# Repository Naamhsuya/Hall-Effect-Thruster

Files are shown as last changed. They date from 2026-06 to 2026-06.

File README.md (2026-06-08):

Hall Effect Thruster — Magnetic Field Model

[README.md](https://github.com/user-attachments/files/28627607/README.md)
# Hall Effect Thruster (HET) — Research & Design Project

Scaling analysis, magnetostatic modeling, and CAD design of a Hall Effect Thruster, with an accompanying research manuscript currently under peer review at the **Journal of Engineering and Applied Sciences, Springer Nature**.








---

## Repository Structure

```
├── CAD/                  # SolidWorks part and assembly files
├── FEMM/                 # Magnetic field simulation files (FEMM format)
├── Scaling/              # Thruster scaling analysis spreadsheet (.xlsx)
├── Gallery/              # Miscellaneous project images and visuals
└── REFERENCES.md         # Full list of papers and resources used
```

---

## Project Overview

### 1. Scaling Analysis
Thruster dimensions and operating parameters were derived from Hall thruster scaling laws. The scaling methodology closely follows the work of **Mahajan et al. (2025)** on 500W-class Hall thruster development. The spreadsheet in `Scaling/` documents the computed parameters used to size the thruster geometry, including discharge channel dimensions, propellant flow rates, and power estimates.

### 2. Magnetic Modeling
Magnetostatic simulations were performed using [FEMM (Finite Element Method Magnetics)](https://www.femm.info/wiki/HomePage). The `.FEM` files in `FEMM/` contain the magnetic circuit geometry, material definitions, and boundary conditions used to shape and optimize the radial magnetic field profile across the discharge channel.

### 3. CAD Design
A 3D model of the thruster was developed in **SolidWorks** based on the scaled parameters and magnetic modeling results. The `CAD/` folder contains individual part files and the full assembly.

### 4. Gallery
The `Gallery/` folder contains miscellaneous project visuals including simulation plots, design iterations, and reference images.
<p align="center">
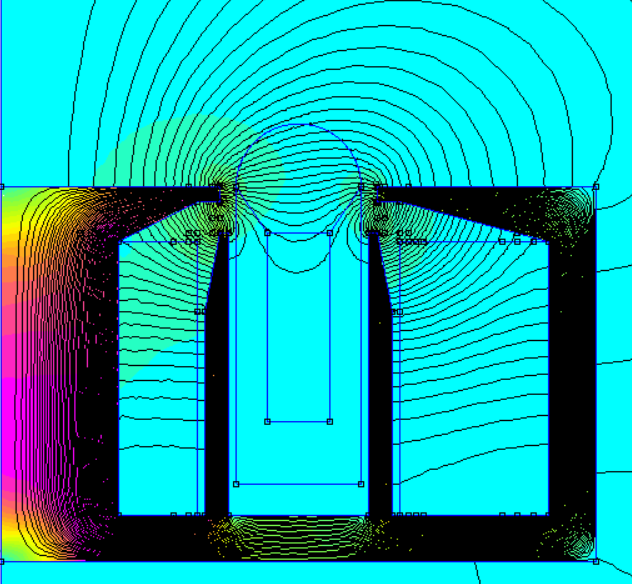
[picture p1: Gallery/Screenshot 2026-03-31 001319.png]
FEMM Magnetic Field Topology
  
  &nbsp;&nbsp;
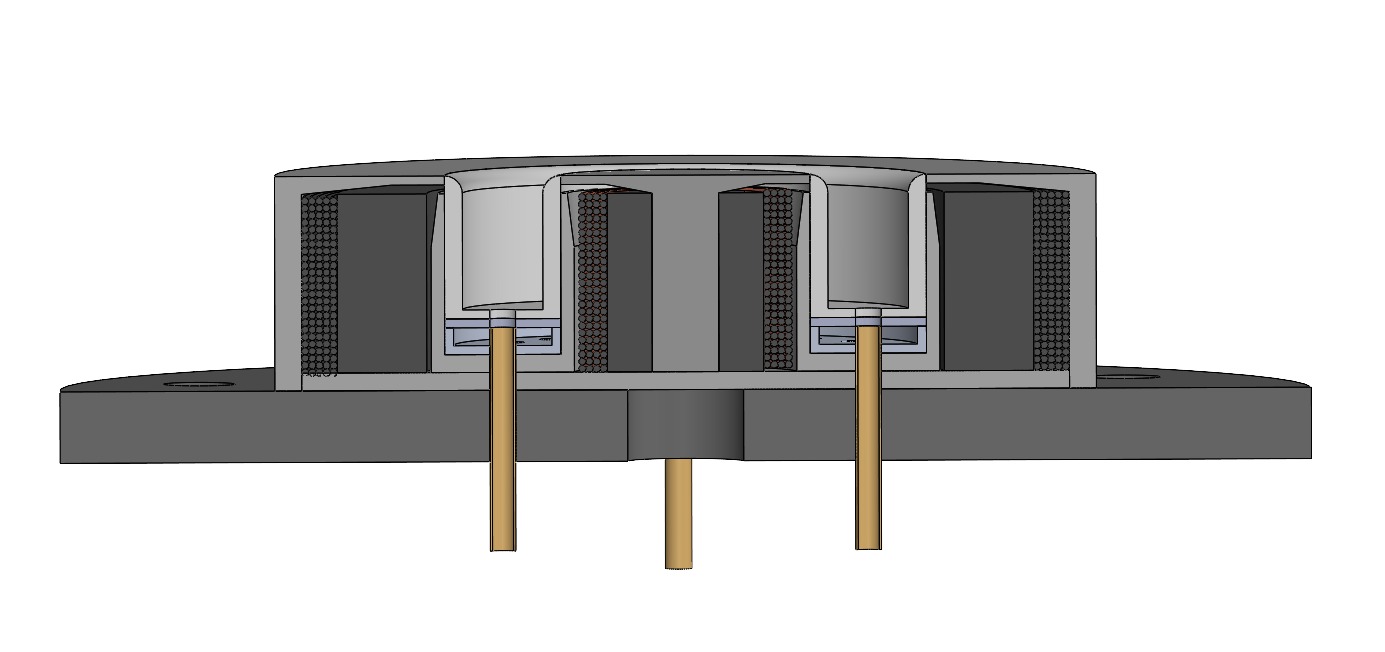
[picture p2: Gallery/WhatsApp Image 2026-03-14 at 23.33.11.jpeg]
SolidWorks Section View
  
</p>
<p align="center">
  <em>Left: FEMM 2D axisymmetric magnetic field topology near channel exit &nbsp;|&nbsp; Right: SolidWorks section view of thruster assembly</em>
</p>

<p align="center">
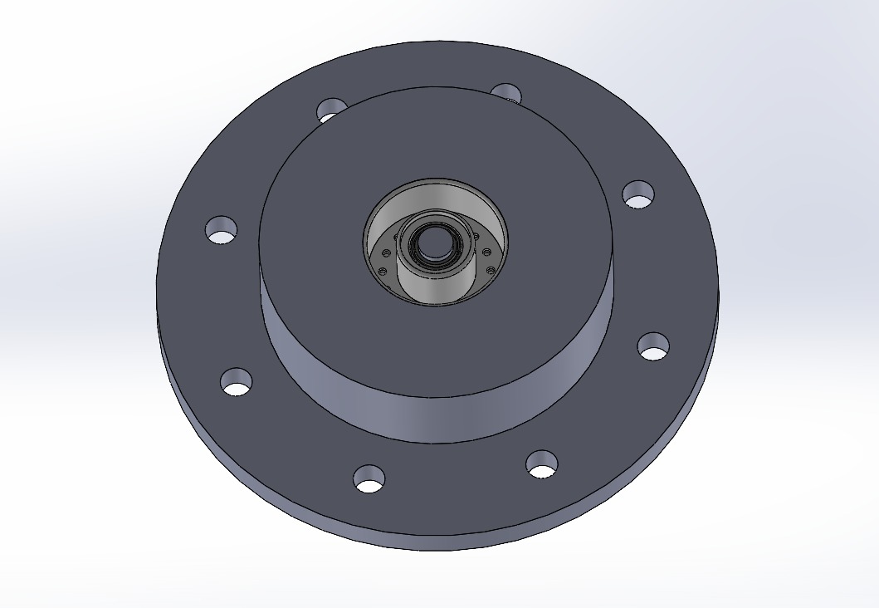
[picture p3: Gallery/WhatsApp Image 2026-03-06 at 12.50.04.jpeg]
Isometric CAD View
  
  &nbsp;&nbsp;
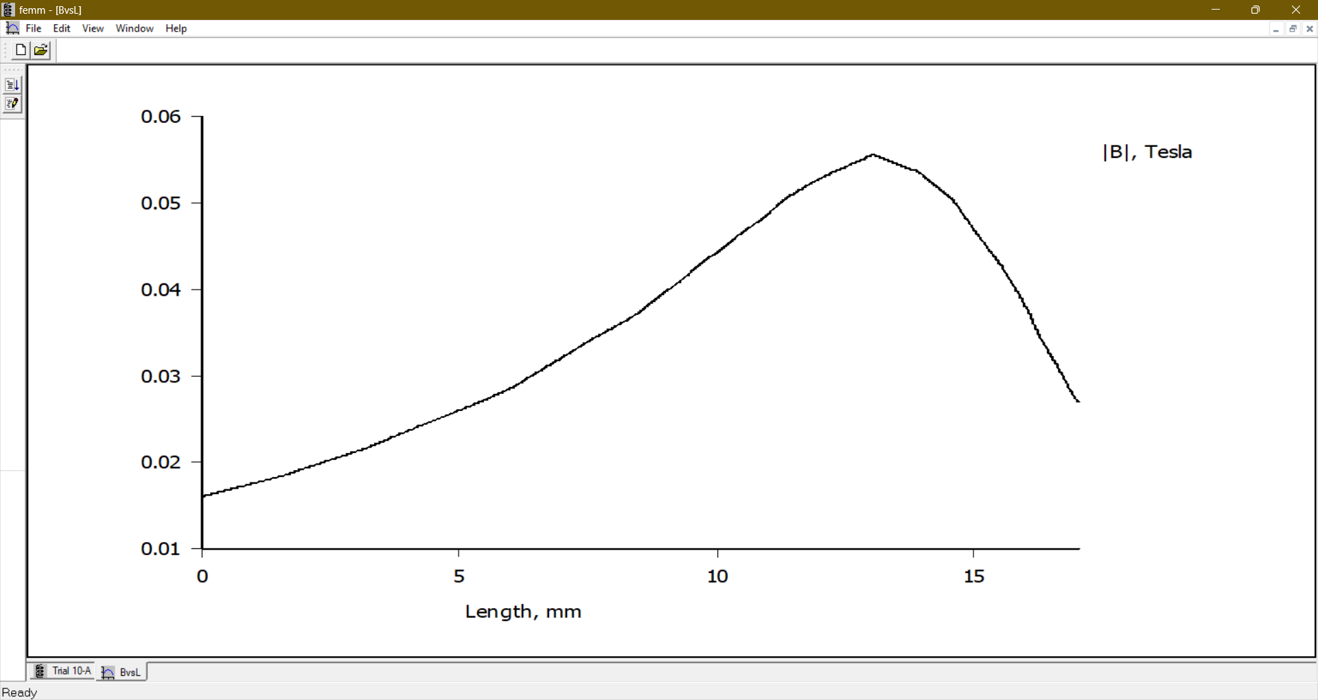
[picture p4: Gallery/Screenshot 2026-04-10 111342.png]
Channel Length vs Magnetic Field Strength
  
</p>
<p align="center">
  <em>Left: Isometric external view of thruster assembly &nbsp;|&nbsp; Right: Channel length vs magnetic field strength regression</em>
</p>
---

## Tools Used

| Tool | Purpose |
|---|---|
| FEMM | Magnetostatic finite element analysis |
| SolidWorks | 3D part and assembly modeling |
| Microsoft Excel | Scaling law calculations |

---

## Results & Key Findings

### Scaling Output — Channel Geometry

A regression-based scaling approach derived from a compiled dataset of 18 low-power Xenon Hall Effect Thrusters was applied to the target operating point of **200 W** and **250 V**. The procedure yielded the following discharge channel dimensions:

| Parameter | Value |
|---|---|
| Mean channel diameter | 38 – 40 mm |
| Channel length | 19 – 21 mm |
| Channel width (height) | ~9 mm |
| Discharge voltage | 250 V |
| Discharge power | 200 W |
| Propellant | Xenon (SPT-type) |

These dimensions place the thruster within the geometric range of compact low-power Xenon HETs, consistent with the SPT-50M and KHT-50 class devices used as reference configurations in the scaling dataset.

### Magnetic Circuit — FEMM Results

A 2D axisymmetric FEMM simulation was used to develop and refine the magnetic circuit. The circuit used an AISI 1020 soft magnetic steel core with inner and outer poles arranged to concentrate the radial magnetic field near the channel exit — the region where electron confinement and Hall current formation are most critical for stable discharge. The design ensured:

- Radial magnetic field concentrated near the channel exit plane
- Inner pole operating below saturation threshold (verified against the AISI 1020 B-H curve)
- Electron Larmor radius much smaller than the channel length (re ≪ L)
- Ion Larmor radius large enough to allow axial acceleration without premature wall contact (ri ≫ L)

### CAD Design — Representative Model

A SolidWorks assembly was developed to verify that all thruster components could be integrated within the 200 W class envelope. Key material selections:

| Component | Material |
|---|---|
| Discharge channel | Boron Nitride (BN) |
| Magnetic core & poles | AISI 1020 soft magnetic steel |
| Structural base plate | Aluminium |
| Electromagnet windings | Copper (0.8 mm diameter) |

### Predicted Performance

Theoretical performance was estimated from the finalised geometry using scaling relations from Lee et al. (2019):

| Parameter | Value |
|---|---|
| Anode mass flow rate | 1.08 mg/s |
| Thrust force | 15.24 mN |
| Specific impulse (Isp) | 1440.28 s |

> **Note:** These are theoretical estimates derived from empirical scaling relations and have not yet been experimentally validated. The design is intended as a preliminary baseline for future fabrication and vacuum testing.

---

## Key References

This project draws heavily from the following works. A complete reference list of all 116 sources is in [`REFERENCES.md`](./REFERENCES.md).

**Primary methodology reference:**
> Mahajan, B., Troise, L., Giannetti, V., Ferrato, E., & Andreussi, T. (2025). *Development of a 500W-class high-voltage argon-fed Hall thruster.* Journal of Electric Propulsion.

**Scaling laws & design:**
> Dannenmayer, K., & Mazouffre, S. (2008). *Sizing of Hall Effect Thrusters with Input Power and Thrust Level: An Empirical Approach.*

> Shagayda, A. A., & Gorshkov, O. A. (2013). *Hall-thruster scaling laws.* Journal of Propulsion and Power, 29(2), 466–474. https://doi.org/10.2514/1.B34650

> Andrenucci, M., Battista, F., & Piliero, P. *Hall Thruster Scaling Methodology.*

**Foundational textbook:**
> Goebel, D. M., & Katz, I. *Fundamentals of Electric Propulsion: Ion and Hall Thrusters.* JPL Space Science and Technology Series.

---

## Related Publications

### Review Paper — *Published Preprint*
**Review of Electric Propulsion Technologies with Emphasis on Hall Effect Thruster for Satellite Operations**
Ayushmaan Badola, Drishya Sarilla
*Engineering Archive (engrXiv), April 2026*
🔗 [https://doi.org/10.31224/6806](https://doi.org/10.31224/6806)

A comparative review of five electric propulsion technologies — PPTs, Electrospray Thrusters, Gridded Ion Engines, Vacuum-Arc Thrusters, and Hall Effect Thrusters — evaluated across thrust-to-power ratio, specific impulse, system complexity, and flight heritage. Establishes HETs as the most viable baseline technology for small satellite propulsion.

---

### Research Manuscript — *Under Peer Review*
An original research manuscript based on this design project has been submitted to the **Journal of Engineering and Applied Sciences, Springer Nature**, and is currently under peer review.

---

## References & Resources

A complete list of all 116 papers, textbooks, and resources used throughout this project is available in [`REFERENCES.md`](./REFERENCES.md).

> The full reference library (~800MB of PDFs) could not be hosted here due to file size. The reference list links to original sources and DOIs wherever available.

---

## Author

**Ayushmaan Badola**

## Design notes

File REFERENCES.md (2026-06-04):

# References & Resources

Complete list of papers, textbooks, and resources used throughout this project. Links to DOIs and source URLs are provided where available.

---

1. Alifano, F., Panelli, M., & Battista, F. (2023). Preliminary Design Tool for Medium-Low-Power Gridded Ion Thrusters. *Applied Sciences (Switzerland), 13*(9). https://doi.org/10.3390/app13095600

2. Andrenucci, M., Battista, F., & Piliero, P. (n.d.). *Hall Thruster Scaling Methodology.*

3. Antropov, N. N., et al. (2017). Development of Russian Next-generation Ablative Pulsed Plasma Thrusters. *Procedia Engineering, 185*, 53–60. https://doi.org/10.1016/j.proeng.2017.03.291

4. Aoyagi, J., et al. (2025). Series development of coaxial pulsed plasma thruster from 1 J to 8 J. *Journal of Electric Propulsion, 4*(1). https://doi.org/10.1007/s44205-025-00135-z

5. Baird, M. (2016). *Designing an Accessible Hall Effect Thruster.* https://scholarworks.wmich.edu/honors_theses/2697

6. Battista, F., Andrenucci, M., et al. (2007). *High Power Hall Thrusters Design Options.* 30th International Electric Propulsion Conference. https://www.researchgate.net/publication/237630343

7. Battista, F., Andrenucci, M., et al. (2007). *A Review of the Hall Thruster Scaling Methodology.* https://www.researchgate.net/publication/242248186

8. Bock, D., et al. (2016). Development and testing of electric propulsion systems at TU Dresden. *52nd AIAA/SAE/ASEE Joint Propulsion Conference.* https://doi.org/10.2514/6.2016-4848

9. Boeuf, J. P. (2017). Tutorial: Physics and modeling of Hall thrusters. *Journal of Applied Physics, 121*(1). https://doi.org/10.1063/1.4972269

10. Chhavi, C., & Walker, M. L. R. (2024). Review of non-conventional Hall effect thrusters. *Journal of Electric Propulsion, 3*(1). https://doi.org/10.1007/s44205-024-00073-2

11. Choueiri, E. Y. (2009). New dawn for electric rockets. *Scientific American, 300*(2), 58–65. https://doi.org/10.1038/scientificamerican0209-58

12. Conversano, R. W., et al. (n.d.). *Overview of the Ascendant Sub-kW Transcelestial Electric Propulsion System (ASTRAEUS).*

13. Conversano, R. W., et al. (2015). Development and initial testing of a magnetically shielded miniature hall thruster. *IEEE Transactions on Plasma Science, 43*(1), 103–117. https://doi.org/10.1109/TPS.2014.2321107

14. Dannenmayer, K. (2013). *Scaling laws and electron properties in Hall effect thrusters.* https://theses.hal.science/tel-00797732

15. Dannenmayer, K., & Mazouffre, S. (2008). Sizing of Hall effect thrusters with input power and thrust level: An Empirical Approach. https://www.researchgate.net/publication/2212736

16. Dannenmayer, K., Mazouffre, S. (n.d.). Elementary scaling laws for the design of low and high power Hall effect thrusters. https://doi.org/10.1051/eu

17. Daren, Y., Yongjie, D., & Zhi, Z. (2005). Improvement on the scaling theory of the stationary plasma thruster. *Journal of Propulsion and Power, 21*(1), 139–143. https://doi.org/10.2514/1.5901

18. de Grys, K., et al. (n.d.). *Development and Testing of a 4500 Watt Flight Type Hall Thruster and Cathode.*

19. Eslava, S. A., et al. (2014). *Design of a Micro-Pulsed Plasma Thruster for 3U Cubesat.* https://www.researchgate.net/publication/261448478

20. Esteves, B., et al. (n.d.). *Experimental and numerical investigation of a gridded ion thruster running with different propellants (I2, Xe, Kr, Ar).*

21. Ferreira, J. L., et al. (2019). Hall plasma thruster development for micro and nano satellites. *Journal of Physics: Conference Series, 1365*(1). https://doi.org/10.1088/1742-6596/1365/1/012026

22. Forster, R., Szulc, M., & Schein, J. (2024). Design of a power processing unit with integrated telemetry for a vacuum arc thruster. *Journal of Electric Propulsion, 3*(1). https://doi.org/10.1007/s44205-024-00074-1

23. Garcia, A. O., Tang, H., & Ren, J. (2020). Scaling Model for SPT and TAL Thrusters. *IEEE Transactions on Plasma Science, 48*(1), 86–98. https://doi.org/10.1109/TPS.2019.2958187

24. Gascon, N., et al. (n.d.). *Preliminary Testing of a Coaxial Hall Thruster with a Diamond Nose Cone.*

25. Giammarinaro, G., & Marconcini, F. (n.d.). *Hall Thruster Scaling — Electric Propulsion II.*

26. Giannetti, V., et al. (2022). Experimental scaling laws for the discharge oscillations and performance of Hall thrusters. *Journal of Applied Physics, 131*(1). https://doi.org/10.1063/5.0070945

27. Goebel, D. M., & Katz, I. (n.d.). *Fundamentals of Electric Propulsion: Ion and Hall Thrusters.* JPL Space Science and Technology Series.

28. Goebel, D. M., Katz, I., & Mikellides, I. G. (n.d.). *Fundamentals of Electric Propulsion, 2nd Edition.*

29. Gondol, N., Drobny, C., Neunzig, O., & Tajmar, M. (n.d.). *Development and Characterization of a Miniature Hall-Effect Thruster using Permanent Magnets.*

30. Gonzalez Del Amo, J. (2019). *Electric Propulsion at the European Space Agency (ESA).* https://www.researchgate.net/publication/335985184

31. Guidi, C., et al. (n.d.). *Iodine Hollow Cathode Development for Electric Propulsion.*

32. Gur Kokal, U. (n.d.). *Development of a Mili-Newton Level Thrust Stand for Thrust Measurements of Electric Propulsion Systems and UK90 Hall Effect Thruster.*

33. Hall, S. J., et al. (n.d.). *High-Power Performance of a 100-kW Class Nested Hall Thruster.*

34. Hofer, R. R. (2004). *Development and Characterization of High-Efficiency, High-Specific Impulse Xenon Hall Thrusters.* http://www.sti.nasa.gov

35. Hopping, E. P., Huang, W., & Xu, K. G. (2021). Small hall effect thruster with 3D printed discharge channel. *Aerospace, 8*(8). https://doi.org/10.3390/aerospace8080227

36. Hsu, A., et al. (2023). *2023 Small Satellite Propulsion Technologies Compendium.* The Aerospace Corporation, DISTRO A Version 1.41.

37. Ito, T., et al. (2007). Experimental characterization of a micro-hall thruster. *Journal of Propulsion and Power, 23*(5), 1068–1074. https://doi.org/10.2514/1.27140

38. Jankovsky, R. S., et al. (2001). *NASA's Hall Thruster Program.* www.sti.nasa.gov

39. Jankovsky, R., & Manzella, D. (1999). *High Power Hall Thrusters.* http://www.sti.nasa.gov

40. Jorns, B. A., et al. (n.d.). *Prediction and Mitigation of the Mode Transition in a Magnetically Shielded Hall Thruster at High-Specific Impulse and Low Power.*

41. Jorns, B. A., Marks, T. A., & Dale, E. (n.d.). *A Predictive Hall Thruster Model Enabled by Data-Driven Closure.*

42. Kamhawi, H., et al. (n.d.). *Overview of Iodine Propellant Hall Thruster Development Activities at NASA Glenn Research Center.* AIAA-2016-4729.

43. Kang, S., et al. (2014). Cathode Power Development of Hall Thruster for Small Satellite using Microwave cathode. *Journal of the Korean Society for Aeronautical & Space Sciences, 42*(11), 974–980. https://doi.org/10.5139/jksas.2014.42.11.974

44. Kim, V. (1998). Main physical features and processes determining the performance of stationary plasma thrusters. *Journal of Propulsion and Power, 14*(5), 736–743. https://doi.org/10.2514/2.5335

45. Kirn, V., et al. (1998). Development and characterization of small SPT. *34th AIAA/ASME/SAE/ASEE Joint Propulsion Conference.* https://doi.org/10.2514/6.1998-3335

46. Kodys, A., & Choueiri, E. (2005). *A Critical Review of the State-of-the-Art in the Performance of Applied-Field Magnetoplasmadynamic Thrusters.* https://doi.org/10.2514/6.2005-4247

47. Krejci, D., et al. (n.d.). *Development, Production, and Testing of the IFM Nano FEEP Thruster.* https://www.researchgate.net/publication/336020667

48. Kuhn, M., Toursel, C., & Schein, J. (2021). Thrust measurements on the high efficient and reliable vacuum arc thruster (Hervat). *Applied Sciences, 11*(5). https://doi.org/10.3390/app11052274

49. Lappas, V., et al. (2011). Micro-electric propulsion solutions for small satellite missions. *2nd International Conference on Space Technology, ICST 2011.* https://doi.org/10.1109/ICSpT.2011.6064668

50. Lascombes, P., Fiorentino, A., & Dewost, P. (n.d.). *Electric Propulsion for Small Satellites: A Case Study.*

51. Lee, D., et al. (2021). *Development and Performance Test of a 50 W-class Hall Thruster.* https://www.researchgate.net/publication/352908476

52. Lee, E., et al. (2019). Scaling approach for sub-kilowatt hall-effect thrusters. *Journal of Propulsion and Power, 35*(6), 1073–1079. https://doi.org/10.2514/1.B37424

53. Lev, D., et al. (2016). The Development of CAM200 - Low Power Hall Thruster. *Transactions of the Japan Society for Aeronautical and Space Sciences, 14*(ists30). https://doi.org/10.2322/tastj.14.pb_217

54. Lev, D., et al. (n.d.). *Electric Propulsion Activities at Rafael in 2019.* https://www.researchgate.net/publication/337160340

55. Lev, D., et al. (2019). The technological and commercial expansion of electric propulsion. *Acta Astronautica, 159*, 213–227. https://doi.org/10.1016/j.actaastro.2019.03.058

56. Levchenko, I., et al. (2018). Space micropropulsion systems for Cubesats and small satellites. *Applied Physics Reviews, 5*(1). https://doi.org/10.1063/1.5007734

57. Lyne, C. T., Liu, M. F., & Rovey, J. L. (2023). A Brief Review of Electrospray Propulsion Diagnostics. *AIAA SciTech Forum and Exposition, 2023.* https://doi.org/10.2514/6.2023-0263

58. **Mahajan, B., Troise, L., Giannetti, V., Ferrato, E., & Andreussi, T. (2025). Development of a 500W-class high-voltage argon-fed Hall thruster.** ⭐ *Primary methodology reference for this project.*

59. Marianacci, A., & Mazouffre, S. (n.d.). *Machine learning-based Hall Thruster scaling laws.* https://hal.science/hal-04666879v1

60. Matyash, K., et al. (n.d.). *Rotating spoke instabilities in a wall-less Hall thruster: Simulations.* https://doi.org/10.48550/arXiv.1901.10135

61. Mazouffre, S. (n.d.). *Electric propulsion for satellites and spacecraft: established technologies and novel approaches.*

62. Mazouffre, S. (2013). Laser-induced fluorescence diagnostics of the cross-field discharge of Hall thrusters. *Plasma Sources Science and Technology, 22*(1). https://doi.org/10.1088/0963-0252/22/1/013001

63. Mazouffre, S., & Vinci, A. E. (2022). *Effect of magnetic nozzle geometry on ion and electron properties.* https://www.researchgate.net/publication/363860624

64. McDowell, J. C. (2020). The Low Earth Orbit Satellite Population and Impacts of the SpaceX Starlink Constellation. *The Astrophysical Journal Letters, 892*(2), L36. https://doi.org/10.3847/2041-8213/ab8016

65. Mikami, K., Komurasaki, K., & Fujiwara, T. (n.d.). *Optimization of Channel Configuration of Hall Thrusters.*

66. Mikellides, I. G., et al. (2010). Magnetic shielding of the acceleration channel walls in a long-life Hall thruster. *46th AIAA/ASME/SAE/ASEE Joint Propulsion Conference.* https://doi.org/10.2514/6.2010-6942

67. Miller, S., et al. (2021). Survey and performance evaluation of small-satellite propulsion technologies. *Journal of Spacecraft and Rockets, 58*(1), 222–231. https://doi.org/10.2514/1.A34774

68. Misuri, T., & Andrenucci, M. (2008). *HET Scaling Methodology: Improvement and Assessment.*

69. Nurmberger, F., Hock, A., & Tajmar, M. (2015). *Development of a Compact Hall Thruster in the 50–150 Watt Range.* https://doi.org/10.2514/6.2015-3822

70. Oh, B., et al. (2023). Design, fabrication, and testing of an undergraduate hall effect thruster. *Journal of Electric Propulsion, 2*(1). https://doi.org/10.1007/s44205-023-00040-3

71. Oh, D. (2005). *Hall Thruster Technology for NASA Science Missions.* http://www.sti.nasa.gov

72. Oleson, S. R., & Sankovic, J. M. (1998). *Electric Propulsion for Low Earth Orbit Constellations.* http://www.sti.nasa.gov

73. O'Reilly, D., et al. (2021). Electric propulsion methods for small satellites: A review. *Aerospace, 8*(1). https://doi.org/10.3390/aerospace8010022

74. O'Reilly, D., et al. (2023). A Coaxial Pulsed Plasma Thruster Model with Efficient Flyback Converter Approaches for Small Satellites. *Aerospace, 10*(6). https://doi.org/10.3390/aerospace10060540

75. Pal, D., et al. (2021). *Hall-Effect Thruster (HET).* www.irjet.net

76. Pinero, L. R., et al. (n.d.). *Development of High-Power Hall Thruster Power Processing Units at NASA GRC.*

77. Potrivitu, G.-C. (2014). *Design and Computational Analysis of a Hall Effect Thruster Using a Novel Dimensioning Tool.* https://doi.org/10.13140/RG.2.2.34963.07202

78. Ragsac, R. V., et al. (1968). *A Handbook for the Study of Electric Propulsion Systems.*

79. Raitses, Y., & Fisch, N. J. (2001). Parametric investigations of a nonconventional Hall thruster. *Physics of Plasmas, 8*(5 II), 2579–2586. https://doi.org/10.1063/1.1355318

80. Shagayda, A. A. (2015). On scaling of Hall effect thrusters. *IEEE Transactions on Plasma Science, 43*(1), 12–28. https://doi.org/10.1109/TPS.2014.2315851

81. Shagayda, A. A., & Gorshkov, O. A. (2013). Hall-thruster scaling laws. *Journal of Propulsion and Power, 29*(2), 466–474. https://doi.org/10.2514/1.B34650

82. Shumeiko, A., Telekh, V., & Ryzhkov, S. (2025). Thrust-vectoring schemes for electric propulsion systems: A review. *Chinese Journal of Aeronautics, 38*(6). https://doi.org/10.1016/j.cja.2025.103401

83. Simmonds, J. B., et al. (2024). Magnetically Shielded Miniature Hall Thruster: Flight Qualification, LIF, and Krypton Performance. *AIAA SciTech Forum and Exposition, 2024.* https://doi.org/10.2514/6.2024-2166

84. Singh, S., et al. (n.d.). *Introduction to Plasma Based Propulsion System: Hall Thrusters.* www.intechopen.com

85. Stark, W., Gondol, N., & Tajmar, M. (2022). Concept and design of a hall-effect thruster with integrated thrust vector control. *Journal of Electric Propulsion, 1*(1). https://doi.org/10.1007/s44205-022-00023-w

86. Stark, W., Neunzig, O., & Tajmar, M. (2025). Development of a Hall-effect thruster with integrated thrust vector control, concept and test results. *Journal of Electric Propulsion, 4*(1). https://doi.org/10.1007/s44205-025-00138-w

87. Su, L. L., Vazsonyi, A. R., & Jorns, B. A. (2020). Performance of a 9-kW magnetically-shielded hall thruster with krypton. *AIAA Propulsion and Energy 2020 Forum.* https://doi.org/10.2514/6.2020-3617

88. Szabo, J., et al. (2016). High throughput 600 Watt Hall Effect Thruster for space exploration. *52nd AIAA/SAE/ASEE Joint Propulsion Conference.* https://doi.org/10.2514/6.2016-4830

89. van 't Klooster, T. G. E. (2018). *Electric Micro Propulsion — Development of a LaB6 Cathode for Micro Electric Thrusters.*

90. Vanwoerkom, M., et al. (n.d.). *Test Results of ExoTerra's Halo Micro Electric Propulsion System.*

91. Villegas-Prados, D., et al. (2024). Emission and performance characterization of ionic liquids for an externally wetted electrospray thruster. *Acta Astronautica, 219*, 97–107. https://doi.org/10.1016/j.actaastro.2024.03.013

92. Walker, Q. E., et al. (n.d.). Arcjet Neutralization of Hall Thrusters, Part 2: Experimental Demonstration. *Journal of Spacecraft and Rockets, 41*(6).

93. Wang, W. C., et al. (2023). Development of heaterless hollow cathode for low-power Hall thruster. *2023 IEEE ICARES.* https://doi.org/10.1109/ICARES60489.2023.10329902

94. Warner, N. Z. (2007). *Theoretical and Experimental Investigation of Hall Thruster Miniaturization.*

95. Wertz, J. R., & Larson, W. J. (1999). *Space Mission Analysis and Design.* Microcosm / Springer.

96. Zhuang, T., et al. (n.d.). *Micro-Cathode Arc Thruster Development and Characterization.*

---

> ⭐ Entries marked with a star were primary references that directly shaped the design methodology of this project.

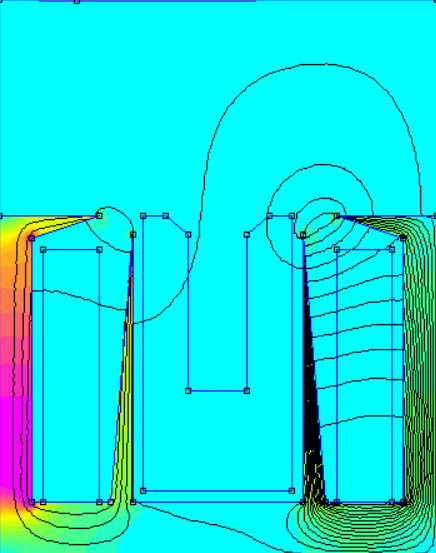
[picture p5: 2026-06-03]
Gallery/Screenshot 2026-01-05 160842.png

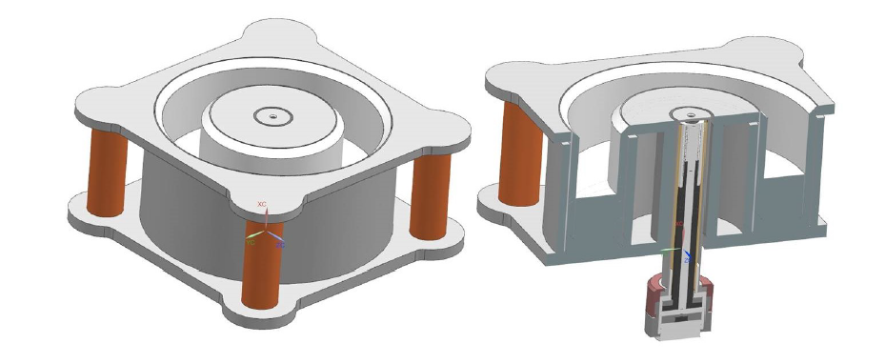
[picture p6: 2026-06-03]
Gallery/Screenshot 2025-08-01 022618.png

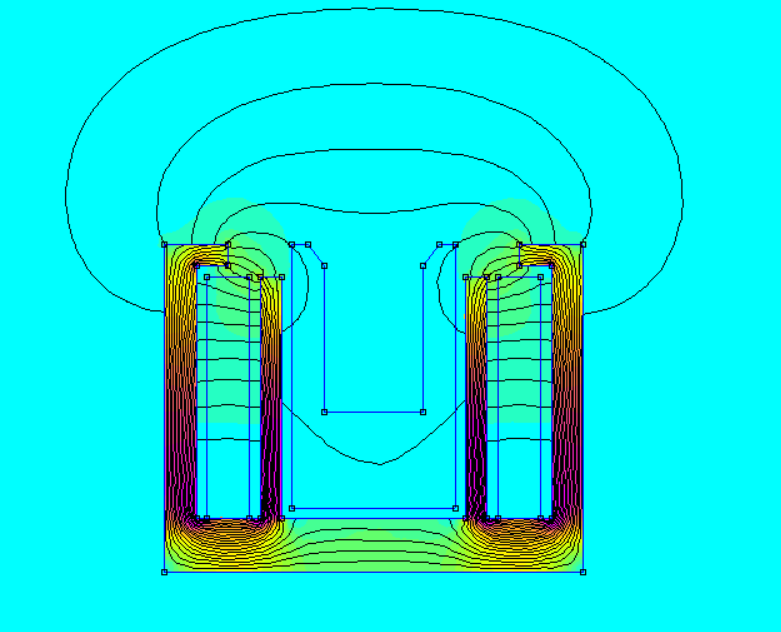
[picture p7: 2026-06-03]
Gallery/Screenshot 2026-01-07 040005.png

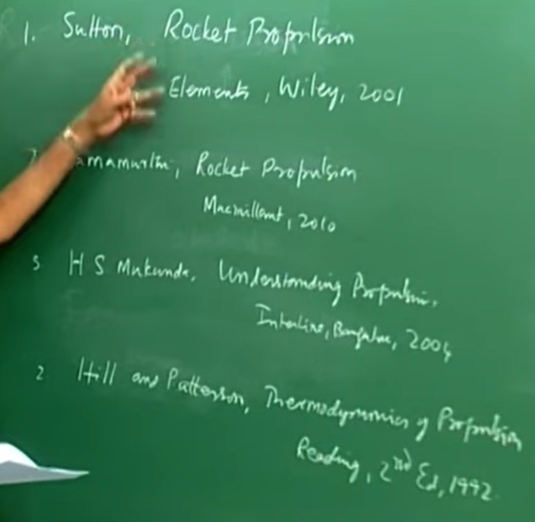
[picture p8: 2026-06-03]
Gallery/Screenshot 2025-07-25 173830.png

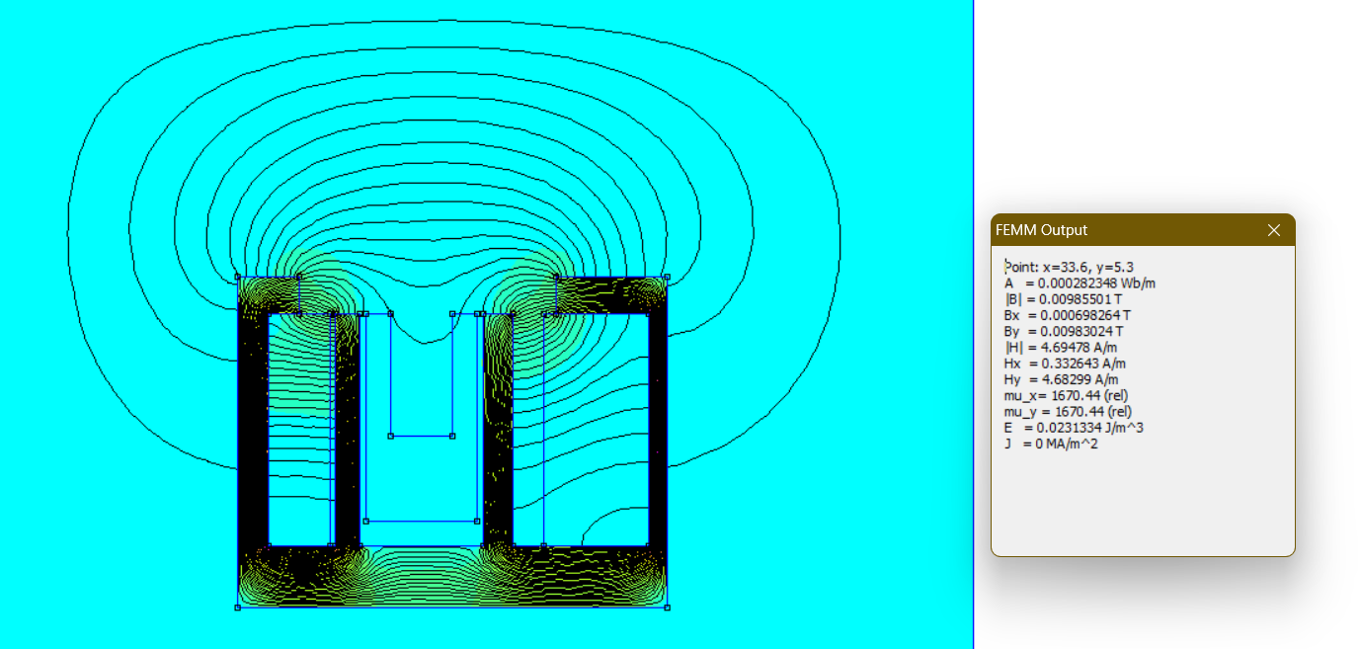
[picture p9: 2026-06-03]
Gallery/Screenshot 2026-01-20 001124.png

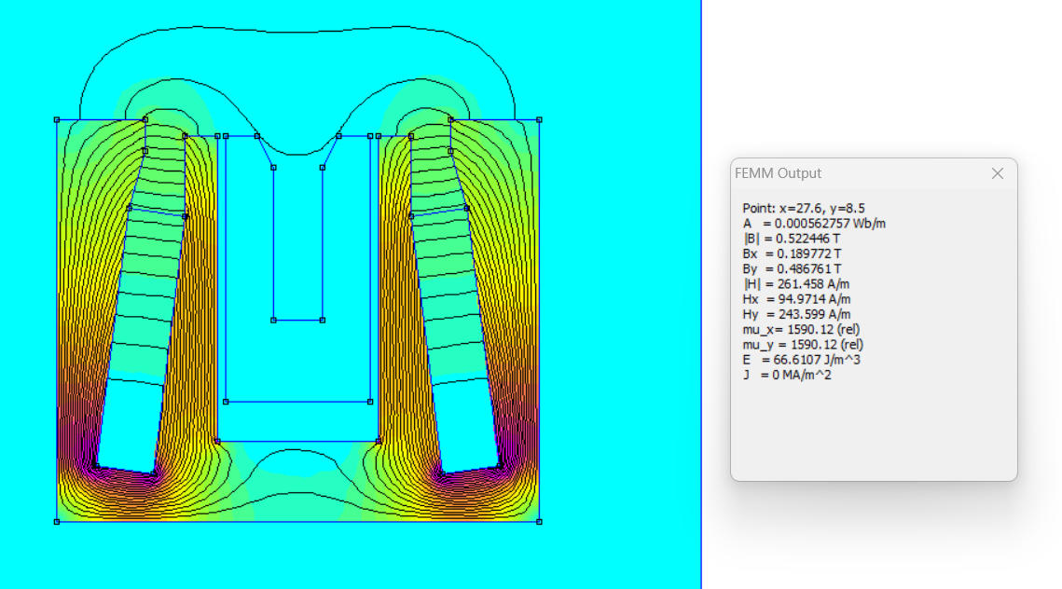
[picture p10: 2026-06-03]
Gallery/Screenshot 2026-01-10 013145.png

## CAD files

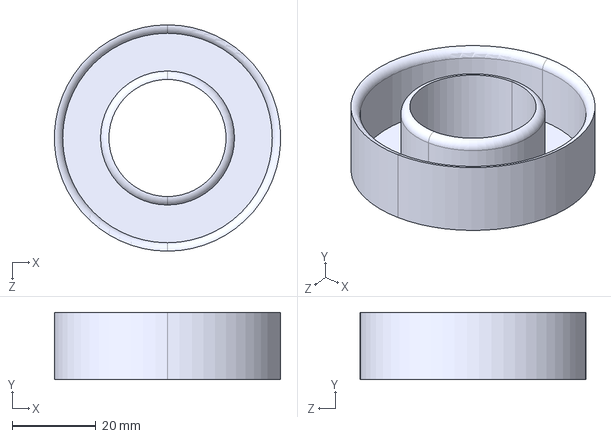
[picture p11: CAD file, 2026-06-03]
Parts/BN Channel.STEP
53.8 x 16.0 x 53.9 mm

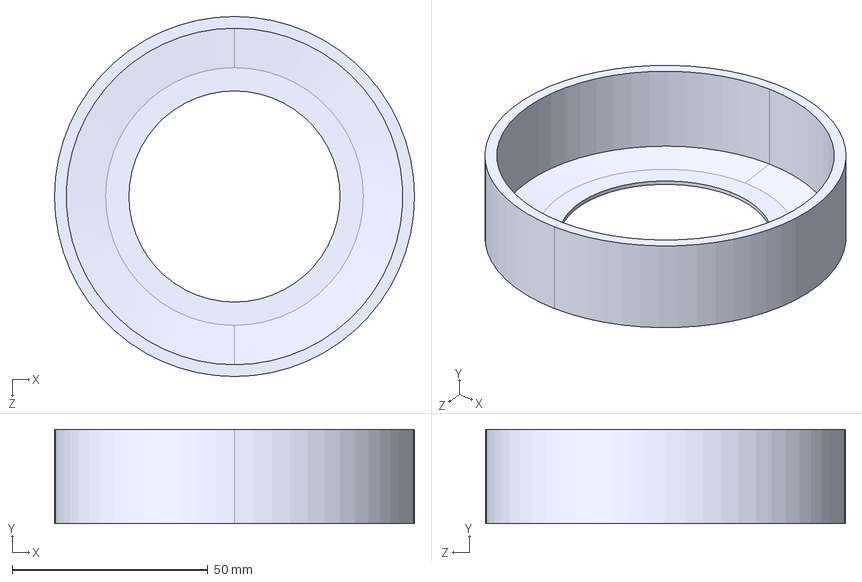
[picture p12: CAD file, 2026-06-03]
Parts/Outer Layer.STEP
91.9 x 24.0 x 91.9 mm

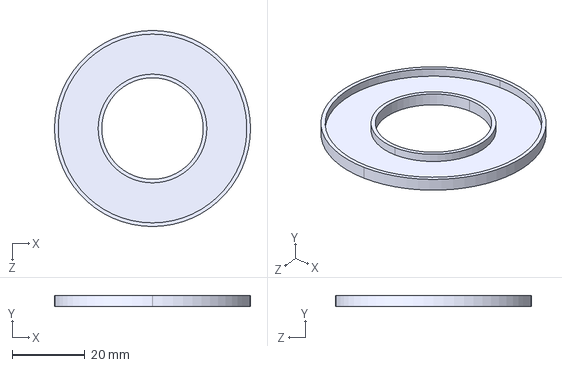
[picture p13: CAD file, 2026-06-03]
Parts/Anode Plate 2.STEP
53.9 x 3.00 x 53.9 mm

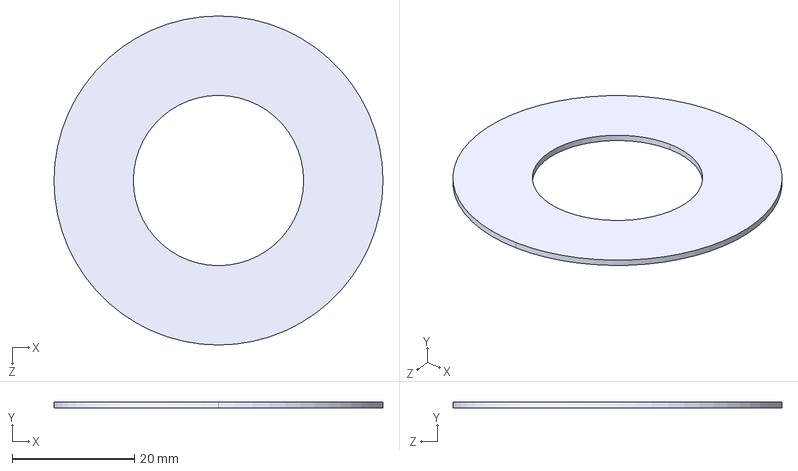
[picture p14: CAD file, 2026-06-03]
Parts/Anode Plate 1.STEP
53.9 x 1.00 x 53.9 mm

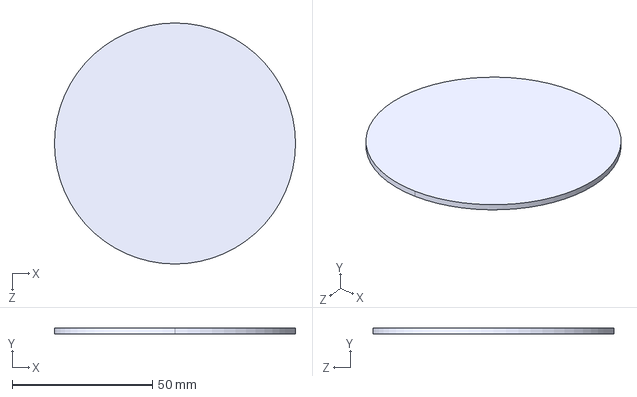
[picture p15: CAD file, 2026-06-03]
Parts/Outer Layer 2.STEP
85.9 x 2.00 x 85.9 mm

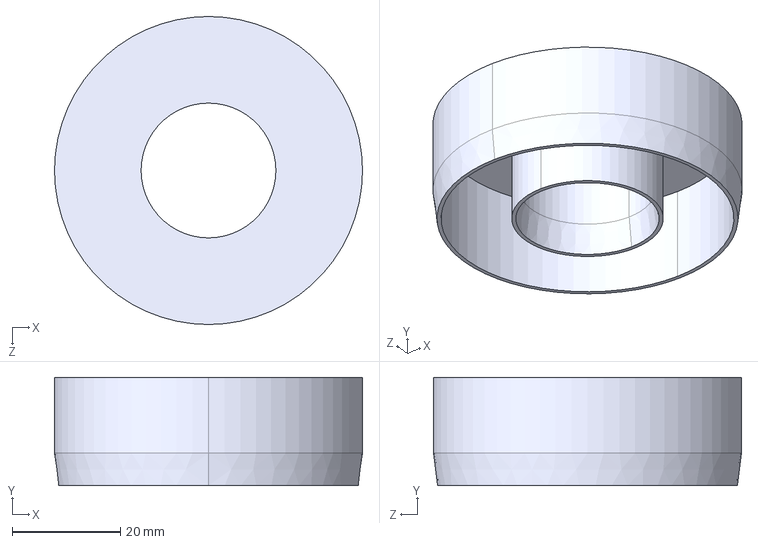
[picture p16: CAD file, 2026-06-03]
Parts/Channel.STEP
56.9 x 20.0 x 56.9 mm

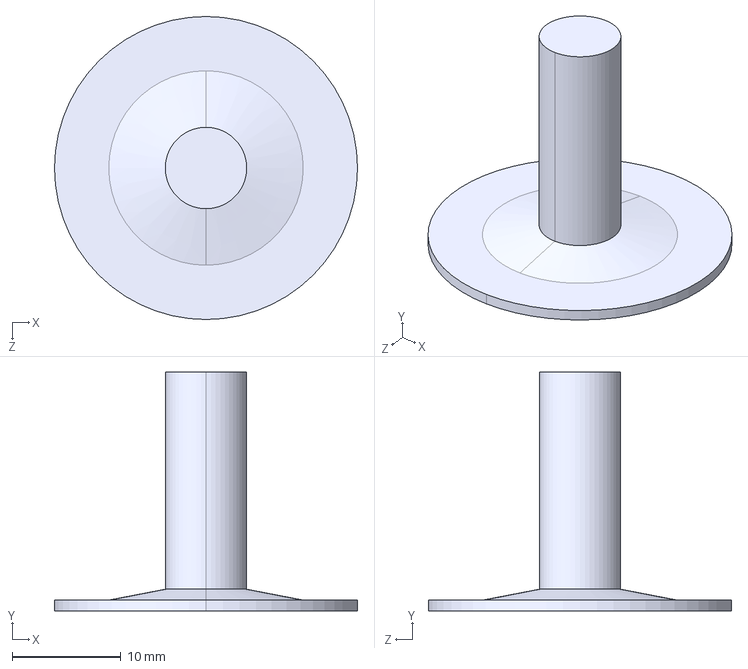
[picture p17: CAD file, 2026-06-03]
Parts/Innermost Part.STEP
27.9 x 22.0 x 27.9 mm

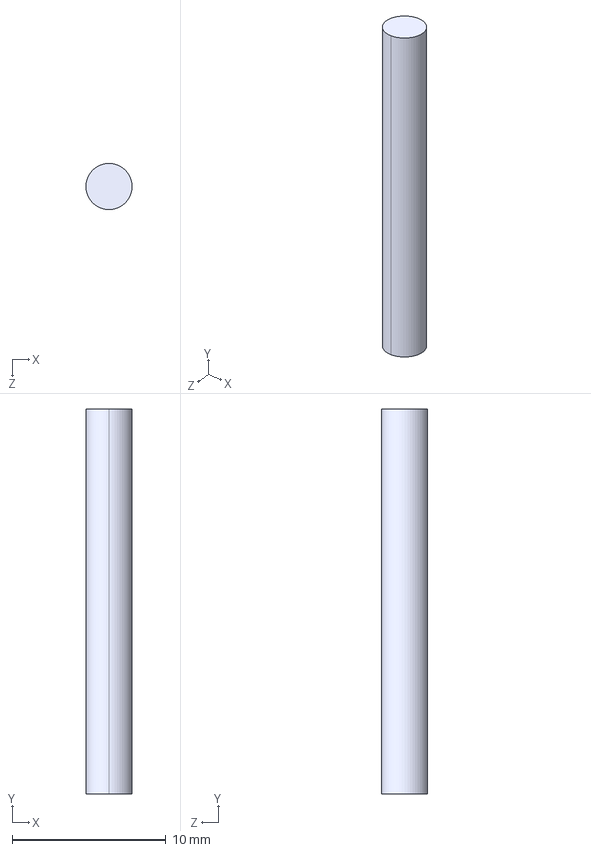
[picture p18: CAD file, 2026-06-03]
Parts/Anode Post.STEP
3.00 x 25.0 x 3.00 mm

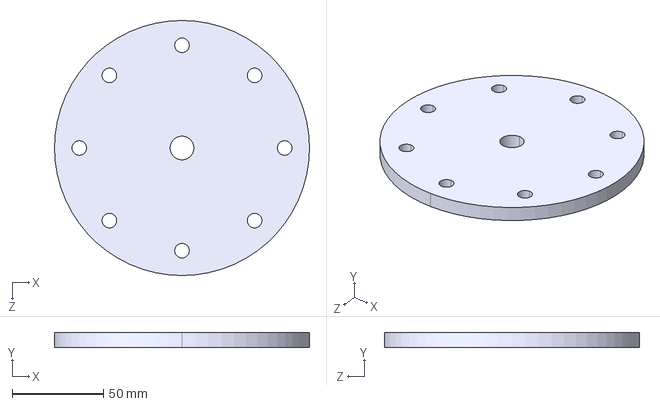
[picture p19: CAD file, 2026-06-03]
Parts/Mounting.STEP
140.0 x 8.00 x 140.0 mm

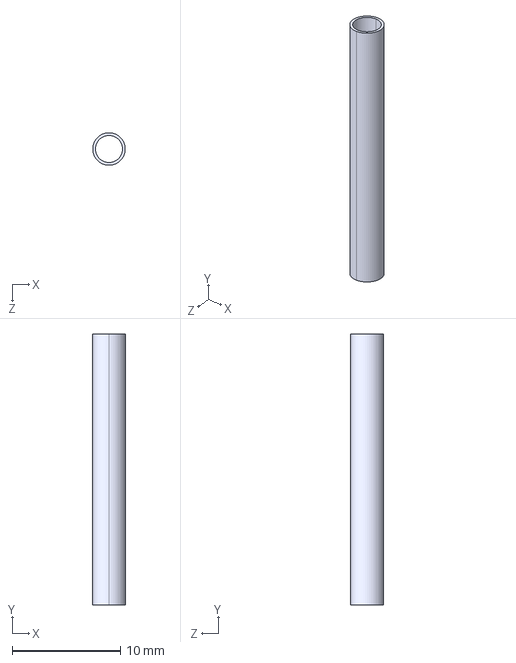
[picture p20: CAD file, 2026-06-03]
Parts/Propellant Feed Pipe.STEP
3.00 x 25.0 x 3.00 mm

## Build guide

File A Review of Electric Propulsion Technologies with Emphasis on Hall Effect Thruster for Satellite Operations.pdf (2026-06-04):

# Review of Electric Propulsion Technologies with Emphasis on Hall Effect Thruster for Satellite Operations

Ayushmaan Badola¹

and Drishya Sarilla¹ | Venkatesh S.

2

Department of Aeronautical Engineering | Department of Aeronautical Engineering
Sathyabama Institute of Science and Technology | Sathyabama Institute of Science and Technology
Chennai, Tamil Nadu 600119, India | Chennai, Tamil Nadu 600119, India
ayushmaanbadola@gmail.com | mitvenkatesh@gmail.com

Abstract - The exponential growth of small satellite deployments and the increasing density of orbital debris necessitate compact, efficient, and sustainable propulsion systems capable of executing precise maneuvers and extended operational lifetimes. While traditional chemical propulsion is limited by severe size and efficiency constraints, scaling down complex electric propulsion (EP) systems for power-constrained micro-platforms introduces significant engineering challenges. This paper presents a comprehensive review and comparative analysis of five leading electric propulsion technologies: Pulsed Plasma Thrusters (PPTs), Electrospray Thrusters, Gridded Ion Engines, Vacuum-Arc Thrusters (VATs), and Hall-Effect Thrusters (HETs). These systems are evaluated across critical mission parameters, including thrustto-power ratio, specific impulse, system complexity, and flight heritage. The analysis demonstrates that while technologies like PPTs and Electrosprays serve niche ultra-low-power roles, Hall-Effect Thrusters provide the optimal balance of scalable thrust, efficiency, and integration feasibility. Ultimately, this study establishes HETs as the most viable baseline technology for modular small satellite propulsion systems tasked with orbit maintenance, collision avoidance, and decommissioning.

Keywords - Electric Propulsion, Hall-Effect Thrusters (HET),
Small | Satellite | Propulsion, | Micro-thrusters, | Orbital
Maneuvering, Propulsion Systems Review.
I. INTRODUCTION

The rapid expansion of satellite technology and the deployment of vast small-satellite constellations have created an urgent demand for efficient, low-mass, and sustainable in-space propulsion systems. Traditional chemical propulsion, while historically effective, is fundamentally limited by high propellant consumption, restrictive mass fractions, and brief operational lifespans, rendering it increasingly unsuitable for long-term micro-satellite operations.

Electric propulsion (EP), which utilizes electrical energy to accelerate charged particles, offers a significantly higher specific impulse and greater propellant efficiency. This makes EP the premier choice for critical orbital operations, including station-keeping, orbit raising, and fine attitude control. However, selecting the appropriate EP technology for a small satellite involves navigating strict limits on available power, physical volume, and allowable system complexity.

This paper provides a systematic review of the electric propulsion landscape for small satellites. It evaluates the operational mechanisms, performance metrics, and flight heritage of five primary technologies: Pulsed Plasma Thrusters (PPTs), Electrospray Thrusters, Gridded Ion Engines, Vacuum-Arc Thrusters (VATs), and Hall-Effect Thrusters (HETs). By conducting a comparative analysis of these systems, this study aims to identify the most adaptable and efficient propulsion architecture for power-constrained spacecraft. Specifically, it highlights how Hall-Effect Thrusters stand out as a highly versatile option, delivering the continuous, controllable thrust required to meet the evolving maneuverability and debris mitigation needs of modern satellite missions.

II. LITERATURE REVIEW

Electric propulsion (EP) has steadily emerged as the enabling technology for small satellite missions requiring efficient orbit maintenance, attitude control, and debris avoidance. Early studies, such as those by Jahn [1], established the theoretical foundations of EP, demonstrating its superior specific impulse compared to chemical propulsion. Sutton and Biblarz [2] extended this by benchmarking electric systems against conventional chemical alternatives, revealing their advantages in lifetime and propellant efficiency for deep-space and long-duration missions.

Among EP technologies, Pulsed Plasma Thrusters (PPTs) were among the first to fly on small spacecraft, with Mueller
[3] documenting their successful integration on early CubeSat missions. PPTs are valued for simplicity and robustness but suffer from low efficiency and limited continuous thrust capability. Electrospray thrusters, extensively studied by Lozano and colleagues at MIT [4], provide extremely fine thrust control with low power consumption, making them attractive for precision maneuvers, though emitter erosion remains a key limitation.

Gridded ion engines, with their high specific impulse and flight heritage on missions such as DART and Deep Space 1, have been described comprehensively by Goebel and Katz [5]. However, their large power and volume requirements hinder adoption in CubeSats. Vacuum Arc Thrusters (VATs), explored in works by Anders and Andersson [6], represent a compact alternative, but cathode erosion and lack of extensive flight heritage keep their TRL low.

Finally, Hall Effect Thrusters | (HETs) | have gained
prominence as a balanced solution, combining moderate thrust, high efficiency, and scalability. Jorns et al. [7] and Hofer [8] demonstrated their adaptability to CubeSat platforms, while Lev [9] investigated cylindrical geometries for miniaturization. NASA Glenn’s work on magnetic shielding (Sovey [10]) further extended HET lifetimes by mitigating wall erosion, strengthening their suitability for operational small satellite constellations.

Despite this progress, most comparative studies treat these propulsion systems in isolation, with limited emphasis on scalability, modularity, and integration into power-constrained spacecraft. This paper addresses that gap by providing a unified review and comparative analysis of major EP technologies, with a focus on why Hall Effect Thrusters stand out for modular small satellite propulsion.

III. COMPARATIVE ANALYSIS

A systematic comparison of five leading electric propulsion technologies, Pulsed Plasma Thrusters (PPTs), Electrospray Thrusters, Gridded Ion Engines, Hall-Effect Thrusters (HETs), and Vacuum-Arc Thrusters (VATs), was conducted to evaluate their suitability for small satellite maneuvering. Each technology differs significantly in thrust capability, efficiency, power consumption, complexity, and heritage. Table 1 provides a consolidated overview across major performance parameters.

Pulsed Plasma Thrusters (PPT)

Description | and | Working | Principle:
Pulsed Plasma Thrusters operate by ablating a solid polymer propellant bar made of polytetrafluoroethylene (PTFE, commonly known as Teflon) through rapid electrical discharges. Each discharge pulse forms a plasma sheet from the ablated propellant material, which is accelerated primarily by the self-induced Lorentz force (J x B) generated between current-carrying electrodes and their magnetic fields. The system fires these discrete impulse bits at repetition rates that can be controlled from a few pulses per second to thousands. Core components include the PTFE bar, a spark plug igniter, paired electrodes, a pulse-forming network (capacitors and fast electrical switches), and a compact power processing unit (PPU).

Typical Performance in a Micro/Small Satellite Envelope:

Thrust produced is about 10 to 800 µN per thruster head and is scalable by clustering multiple units. Specific Impulse (Isp) is approximately 600–1200 seconds, with modern designs occasionally exceeding this. Average power consumed is between 1–10 W, with pulsed high-peak currents and duty cycle limitations. Flight units typically achieve about 5–10% efficiency, optimal for ultra -low-power applications.

Current | being | employed | by:
NASA’s EO-1 mission successfully flew PPTs to provide highprecision attitude control, demonstrating efficient torque generation as an alternative to reaction wheels, while confirming manageable thruster plume and electromagnetic interference on orbit. FalconSAT-3 equipped with four Busek micro-PPTs set a precedent for low size, weight, and power (SWaP) pulsed systems on small satellites. Modern PPT efforts, such as the PPTCUP and mini-PPT programs, target orbitkeeping for CubeSa ts with advances in electronics and packaging.
Technological | | | Advantage:
PPTs are the simplest form of electric propulsion that produce real delta-V and precise attitude control with minimal power and mass impact. Their modular, pulsed nature suits powerstarved, mass-constrained spacecraft, making them excellent candidates for micro-propulsion solutions on small satellites.

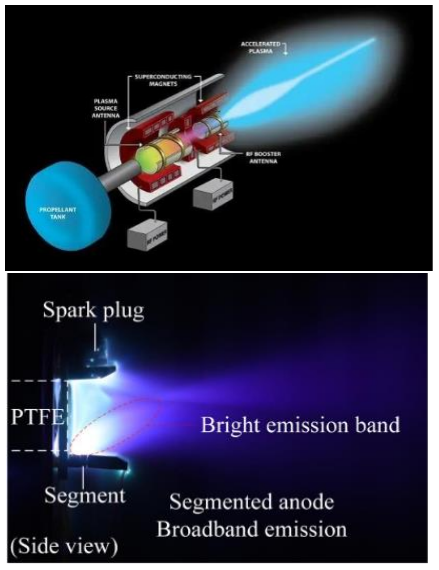
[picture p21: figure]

Fig. 4.2 Components and Operation of PPT

Electrospray Thrusters (Colloid/FEEP)

Description | and | Working | Principle:
Electrospray thrusters operate by forming nanoscale Taylor cones at sharp emitter tips or elongated slits where high electric fields extract ions or charged liquid droplets from ionic liquids or liquid metals (Field Emission Electric Propulsion-FEEP). These charged particles are electrostatically accelerated to produce thrust.

Typical Performance in a Micro/Small Satellite Envelope:

Thrust produced is from micro-Newton up to sub-milli-Newton levels, depending on the array size. Specific Impulse (Isp) ranges from 1000 to 6000 seconds and is tunable for mission requirements. Average power consumed is around sub-watt to a few watts, with excellent precision and throttling capability. The challenges faced include emitter erosion, emission current stability, contamination control, and complex high-voltage packaging.

Current | being | employed | by:
NASA’s LISA Pathfinder mission employed Busek colloid micro-Newton thrusters for drag-free satellite control, setting the standard for thrust precision in space. ENPULSION’s FEEP thrusters hold an extensive in-orbit record with missions performing geostationary orbit transfer and station-keeping. Accion Systems’ TILE electrospray thrusters have been demonstrated on CubeSa t rideshare missions, showcasing increasing commercial adoption.
Technological | Advantage:
Electrospray thrusters deliver extremely fine thrust control at ultra-low power, perfect for precision station-keeping, formation flying, or platforms requiring drag compensation. They are highly advantageous when mission success depends on precise maneuvering within tight power budgets.

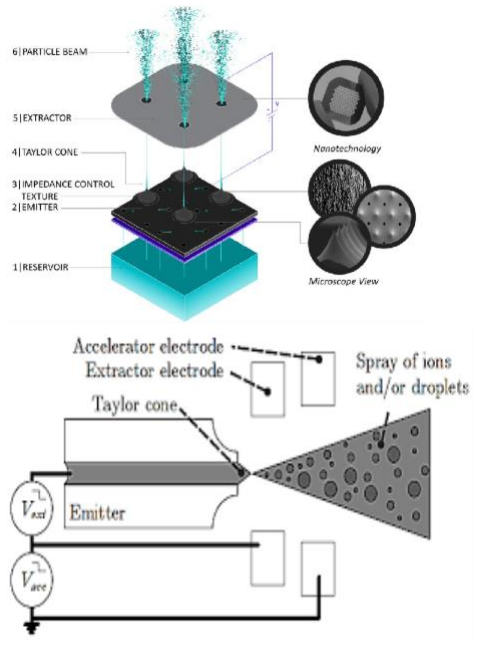
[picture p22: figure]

Fig. 4.3 Components and Operation of Electrospray Thruster

4.6.3 Gridded Ion Thrusters

Description | and | Working | Principle:
Gridded ion engines function by ionizing a noble gas propellant, typically xenon, within a discharge chamber. Ionization may be accomplished by hot-cathode or radio frequency (RF) techniques. Positively charged ions are accelerated through a series of electrostatic grids, achieving exhaust velocities on the order of tens of kilometers per second. A neutralizer emits electrons into the ion beam to avoid spacecraft charging, with magnetic fields confining electrons to enhance ionization efficiency.

Typical Performance:

Thrust produced is approximately 10 mN to over 250 mN, with systems scaling from sub-kilowatt to multi-kilowatt power levels. Specific Impulse (Isp) ranges broadly from 2000 up to 10,000+ seconds, with mission-selectable modes. Power range is typically between 0.5 and 7 kW or more, requiring complex power processing and xenon feed systems.

Currently | being | employed | by:
NASA’s Deep Space-1 demonstrated NSTAR ion thrusters operating over 10,000 hours in flight. The Dawn mission used NSTAR derived thrusters for conducting extended operations around Vesta and Ceres. The European Space Agency’s GOCE satellite utilized QinetiQ’s T5 thruster in drag-free control applications with a record operational duration surpassing 36,000 hours. The BepiColombo mission employs advanced QinetiQ T6 thrusters for Mercury orbit insertion. NASA’s NEXT-C ion thruster has been flight qualified and deployed on missions such as the DART asteroid impactor.
Technological | Advantage:
Gridded ion engines represent the pinnacle of efficiency and durability for missions requiring large total impulse and deep-space delta-V. Despite their power and complexity making them less suitable for very small satellites, they provide benchmark technology for propulsion performance and valuable data for erosion and plume modeling.

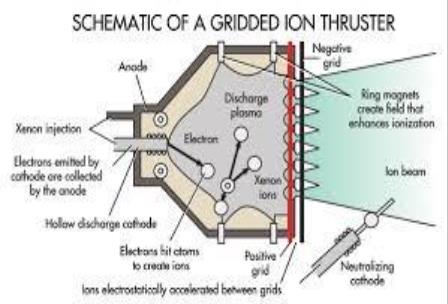
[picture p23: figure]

Fig. 4.4 Components and Operation of Gridded Ion Thruster

4.6.4 Hall-Effect Thrusters (HET)

Description | and | Working | Principle:
Hall-effect thrusters feature a cylindrical | or annular
acceleration channel where electrons are magnetically trapped in an azimuthal current and an axial electric field accelerates ions through E x B effects. A cathode provides electrons that ionize the propellant gas and neutralize the outgoing ion beam plume. Hall thrusters offer simpler, gridless ion acceleration delivering higher thrust-to-power ratios but slightly lower specific impulse (Isp) than gridded ion engines.

Typical Performance:

Thrust produced is about 5 mN up to 300 mN for single channel units. Specific Impulse (Isp) is approximately 1500 to 3000 seconds with xenon, with somewhat lower performance than when using krypton propellant. Power ranges from 100-200 W scaling upward to tens of kilowatts, allowing broad system scalability.

Currently | being | employed | by:
The European SMART-1 lunar mission flew the PPS-1350-G Hall thruster end-to-end for moon transfer. NASA’s Psyche mission applies SPT-140 Hall thrusters for solar-electric propulsion cruise phases. SpaceX Starlink satellites employ mass-produced krypton Hall thrusters across their constellation for orbit raising and maintenance, evidencing high reliability and industrial scale production.

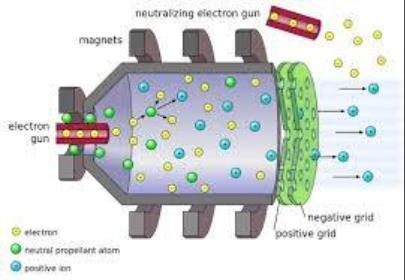
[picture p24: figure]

Technological | Advantage:
HETs deliver an excellent balance of thrust, efficiency, and scalability for small satellite missions. Their mature technology status, ease of integration in modular arrays, and capability for meaningful orbit changes make them ideal for projects needing higher thrust than PPTs while managing medium power budgets.

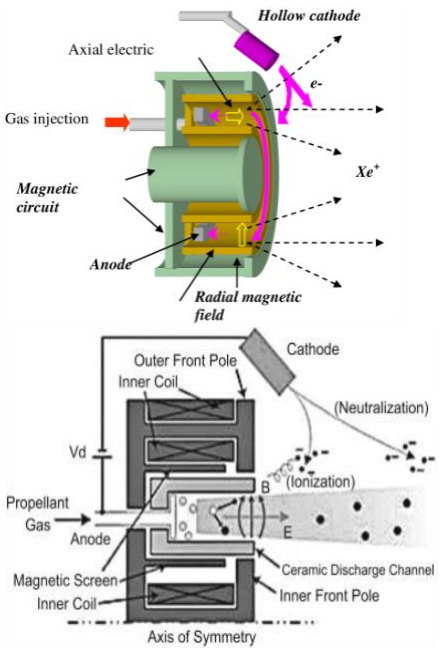
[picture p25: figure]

Fig. 4.6 Components and Operation of HET

4.6.5 Vacuum-Arc Thrusters (VAT)

Description | and | Working | Principle:
Vacuum-Arc Thrusters operate by maintaining a cathodic vacuum arc that vaporizes a solid metallic cathode (commonly titanium or similar metals) into dense plasma. This plasma, created in short, high-current pulses, is ejected and accelerated as discrete impulse bits, similar to PPTs but using solid metal cathode material instead of polymer propellant.

Typical Performance in a Micro/Small Satellite Envelope:

Thrust output is typically in the micro-Newton millisecond range, with also the ability to scale total thrust by arraying multiple µCAT units. It consumes very low average power making it suitable for ultra -compact propulsion needs.

Currently | being | employed | by:
BRICSat-P, flown by the Naval Academy and GWU, implemented a multi-head µCAT system for spacecraft detumbling and attitude control missions, verifying initial flight operations. Research demonstrates evolving power processing and array operation to support CubeSat-scale propulsion, with technology readiness levels progressing through TRL-6 to TRL-7.
Technological | Advantage:
VATs offer exceptional packaging efficiency and simplicity using solid-propellant logistics. Their ultra -compact size and pulsed operation make them ideal for debris remediation buses, emergency in-space delta V, and momentum management on constrained spacecraft, serving as complementary actuators to a main propulsion system.

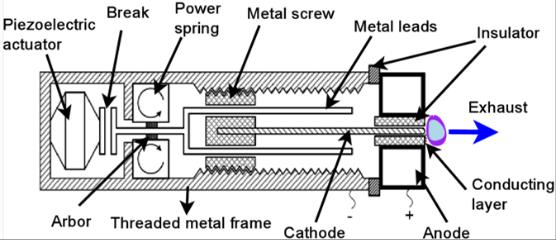
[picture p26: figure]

Fig. 4.7 Components and Operation of VAT

Table 1: Comparative Summary of Electric Propulsion Technologies for Small Satellites

Para meter | Pulsed Plasma Thruster s (PPT) | Electr ospra y Thrus ters | Grid ded Ion Engi nes | Hall-Effect Thruste rs (HET) | Vacuum -Arc Thruste rs (VAT)
Thrust Range | 10–800 µN (clusterab le) | µN to sub-mN | 10– 250+ mN | 5–300 mN (scalabl e) | µN-ms impulse bits (arrays)
Specif ic Impul se (Isp) | 600– 1200 s | 1000– 6000 s | 2000 – 10,00 0+ s | 1500– 3000+ s | Variable impulse bits
Power Requi remen t | 1–10 W average (pulsed peaks) | Sub-watt to few watts | 0.5– 7+ kW | 100 W – multi-kW | Very low average
Syste m Comp lexity | Very low | Mode rate (emitt ers, HV) | High (grid s, feed) | Moderat e to high | Low

Mass and Volu me | Very compact | Low mass, micro -scale | High er (bulk y) | Moderat e | Very compact
Thrust -to-Power Ratio | Moderate | Low to moder ate | Mod erate | High | Low
Flight Herita ge | EO-1, FalconS AT-3 | LISA Pathfi nder, GEO | Deep Spac e-1, Daw n | SMART -1, Starlink, Psyche | BRICSat -P CubeSat
Opera tional Lifeti me | Moderate (propella nt limited) | High (erosi on issues ) | Very high (>10, 000 h) | High (improv ed w/ shieldin g) | Moderat e (erosion-limited)
Suitab ility for Small Sats | Excellent for ultra-small | Excell ent for precis ion | Limit ed (pow er/ma ss) | Excellen t (scalabl e) | Good for attitude/ detumbl e

IV. DISCUSSIONS

The comparative analysis reveals that while each propulsion technology offers unique advantages, their utility for powerand mass-constrained satellite missions varies widely:

Pulsed | Plasma | Thrusters | (PPTs):
Extremely simple and robust, PPTs are best suited for very small satellites requiring ultra -low power operation. Their pulsed operation enables precise impulse control, but their low efficiency and limited continuous thrust restrict their use to attitude control and small orbit maintenance tasks.
Electrospray | Thrusters:
These provide exceptional precision at ultra-low power levels, making them ideal for drag compensation, formation flying, and nanosatellite control. However, their limited thrust output and emitter degradation hinder broader applications where substantial delta -V is required.
Gridded | Ion | Engines:
Ion engines deliver the highest specific impulse and efficiency, making them unparalleled for deep-space, highdelta-V missions. Nevertheless, their large power and volume requirements make them impractical for CubeSats and small satellites, despite their extensive heritage in flagship missions.
Vacuum-Arc | Thrusters | (VATs):
Ultra-compact and simple in design, VATs are useful for attitude control and detumbling in small satellites. However, cathode erosion and low total thrust capability limit their adoption as primary propulsion systems.
Hall-Effect | Thrusters | (HETs):
Offering a balanced compromise between thrust, efficiency, and power consumption, HETs have demonstrated scalability from micro-thrusters (~100 W) to high-power multi-kilowatt units. Their adoption in operational constellations like Starlink proves industrial readiness, while research into magnetic shielding and miniaturization enhances their reliability for small spacecraft. HETs are therefore uniquely suited for missions requiring orbit raising, station-keeping, and collision avoidance under constrained power budgets.
V. KEY FINDINGS

PPTs and Electrosprays excel in ultra -low-power niches but lack sufficient thrust for large maneuvers.

Ion engines dominate in high-delta-V deep space missions but are impractical for small satellites.

VATs remain emerging, with roles limited to complementary control systems.

HETs emerge as the optimal choice, balancing thrust, efficiency, and system integration feasibility, while maintaining proven flight heritage.

Thus, Hall-Effect Thrusters are validated as the most suitable propulsion system for modular small satellite propulsion, enabling scalable designs that align with future constellations and debris-mitigation missions.

VI. FUTURE DIRECTION

While Hall-Effect Thrusters (HETs) present the most balanced option for small satellite propulsion, several technological advancements are still required to maximize their potential:

Miniaturization of HETs: Ongoing research into sub-100 W HETs is critical for CubeSats and nanosatellites. Improved power processing units (PPUs) and micro-fabricated magnetic coils can enhance integration into ultra -compact platforms.

Alternative Propellants: Current reliance on xenon, though effective, is costly and logistically challenging. Propellants such as krypton, iodine, and even atmospheric-breathing concepts in very low Earth orbit (VLEO) are being actively investigated to reduce cost and extend mission lifetimes.

Lifetime Enhancement: Cathode erosion and thermal loading remain limiting factors for long-duration missions. Advanced magnetic shielding, novel cathode designs, and new thermal materials can extend operational lifetimes to match ambitious satellite constellations.

System Integration: Modular HET clusters, when paired with intelligent power management and adaptive thrust control algorithms, can provide reconfigurable propulsion for multirole missions such as station-keeping, collision avoidance, and orbit-raising.

Hybrid Systems: Combining HETs with ultra -low power systems like Electrospray thrusters may enable fine attitude control without sacrificing overall maneuverability. Such hybrid configurations could become the baseline for nextgeneration multi-satellite constellations.

VII. CONCLUSION

This review has provided a comparative assessment of five
major electric | propulsion | technologies—Pulsed | Plasma
Thrusters, Electrospray Thrusters, Gridded Ion Engines, Hall-Effect Thrusters, and Vacuum-Arc Thrusters—focusing on their applicability to small satellite missions.

The analysis highlights that while PPTs and Electrosprays are highly efficient at ultra -low power and precision tasks, they fall short for large-scale orbit changes. Gridded Ion Engines, though extremely efficient and flight-proven, are unsuitable for power- and volume-limited platforms. VATs remain emerging with complementary but limited primary capabilities.

In contrast, Hall-Effect Thrusters strike a unique balance of thrust, efficiency, and scalability, making them the most practical propulsion choice for modular and power-constrained satellites. Their extensive flight heritage, adaptability to new propellants, and ongoing advancements in miniaturization and lifetime management firmly establish them as the propulsion technology of choice for the future of small satellite operations.

ACKNOWLEDGMENT

The authors would like to express their sincere gratitude to Sathyabama Institute of Science and Technology, Chennai, for providing the academic environment and resources to pursue this work. Special thanks are extended to Mr. S. Venkatesh for his continuous guidance and mentorship throughout the project. The authors also acknowledge the contributions of their peers and research colleagues whose discussions and insights have been invaluable in shaping this study.

REFERENCES

[1] Jahn, R.G., Physics of Electric Propulsion (1968).
[2] Sutton, G.P., & Biblarz, O., Rocket Propulsion Elements (2010).
[3] Mueller, J., “Thruster options for microspacecraft: Pulsed Plasma Thrusters” (1997).
[4] Lozano, P., “Electrospray propulsion for small spacecraft” (MIT, 2010).
[5] Goebel, D., & Katz, I., Fundamentals of Electric Propulsion: Ion and Hall Thrusters (JPL, 2008).
[6] Anders, A., Vacuum Arc Thrusters for Space Applications (2008).
[7] Jorns, B.A., “Miniaturization of Hall Thrusters for CubeSats” (2018).
[8] Hofer, R.R., “High-efficiency, high-specific impulse xenon Hall thrusters” (UMich, 2004).
[9] Lev, D., “Cylindrical Hall Thrusters for Miniaturized Satellites” (Princeton, 2013).
[10]Sovey, J.S., “Magnetic shielding in Hall thrusters” (NASA TM, 2004).

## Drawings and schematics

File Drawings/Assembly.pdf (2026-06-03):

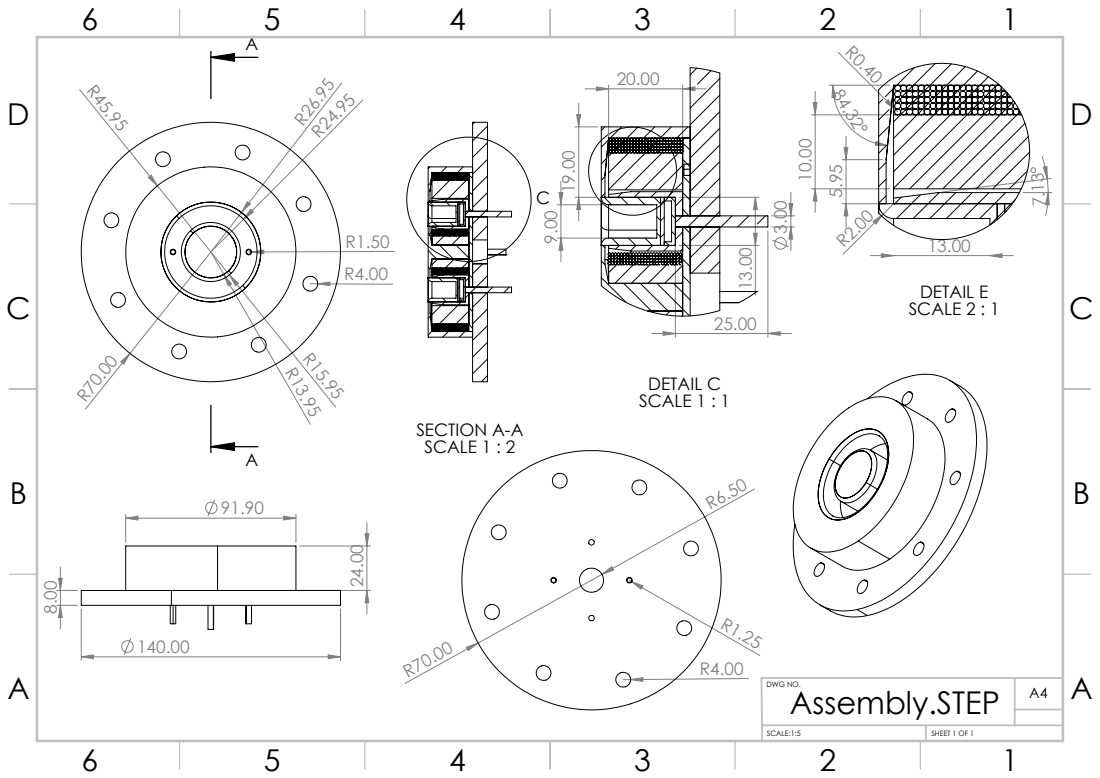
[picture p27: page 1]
SECTION A-A SCALE 1 : 2; DETAIL C SCALE 1 : 1; DETAIL E SCALE 2 : 1; DWG NO.; SCALE:1:5; SHEET 1 OF 1; A4 Assembly.STEP

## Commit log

2026-06-03 CAD Files
    These are CAD files of the basic design of the Hall Thruster. They show basic parts, their fittings, and sizing. These give a little insight into the design and topology of the Hall Thruster.
    [Anode Plate 1.STEP, Anode Plate 2.STEP, Anode Post.STEP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]
2026-06-03 Magnetics
    These are FEMM files of a few of the various trials I performed iteratively for the magnetic topology. It also contains a sample of SPT 100.
2026-06-03 Scaling
    This is the scaling I performed to get the dimensions of my thruster; this methodology is based on studied literature, and this methodology is not my finding. Although there are multiple files showin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
    [HET Scaling (1).xlsx, HET Scaling (2).xlsx, HET Scaling (3).xlsx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]
2026-06-05 Banner Asset
    Image of the actual magnetic topology for Banner.
2026-06-05 Add README for Hall Effect Thruster project
    Added comprehensive project details for the Hall Effect Thruster research and design project, including repository structure, project overview, tools used, results, key findings, references, and auth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

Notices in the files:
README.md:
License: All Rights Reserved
